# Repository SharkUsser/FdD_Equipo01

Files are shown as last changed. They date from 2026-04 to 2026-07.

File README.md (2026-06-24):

# Equipo 01 - Fundamentos de Diseño
### Carrera de Ingeniería Ambiental / Informática / Industrial  
**Universidad Peruana Cayetano Heredia**

---

## Sobre nosotros:  
Somos el **Equipo 01** del curso **Fundamentos de Diseño 2026-1**, conformado por estudiantes de las carreras de Ingeniería Ambiental, Informática e Industrial. 

Nuestro propósito es desarrollar soluciones tecnológicas aplicadas a problemáticas reales del sector agrícola en el Perú, específicamente relacionadas con el uso eficiente del agua y el manejo del suelo. A través de este proyecto, buscamos proponer alternativas innovadoras que permitan mejorar el monitoreo de las condiciones del suelo, optimizar el riego y contribuir a una agricultura más sostenible y productiva.

<p align="center">
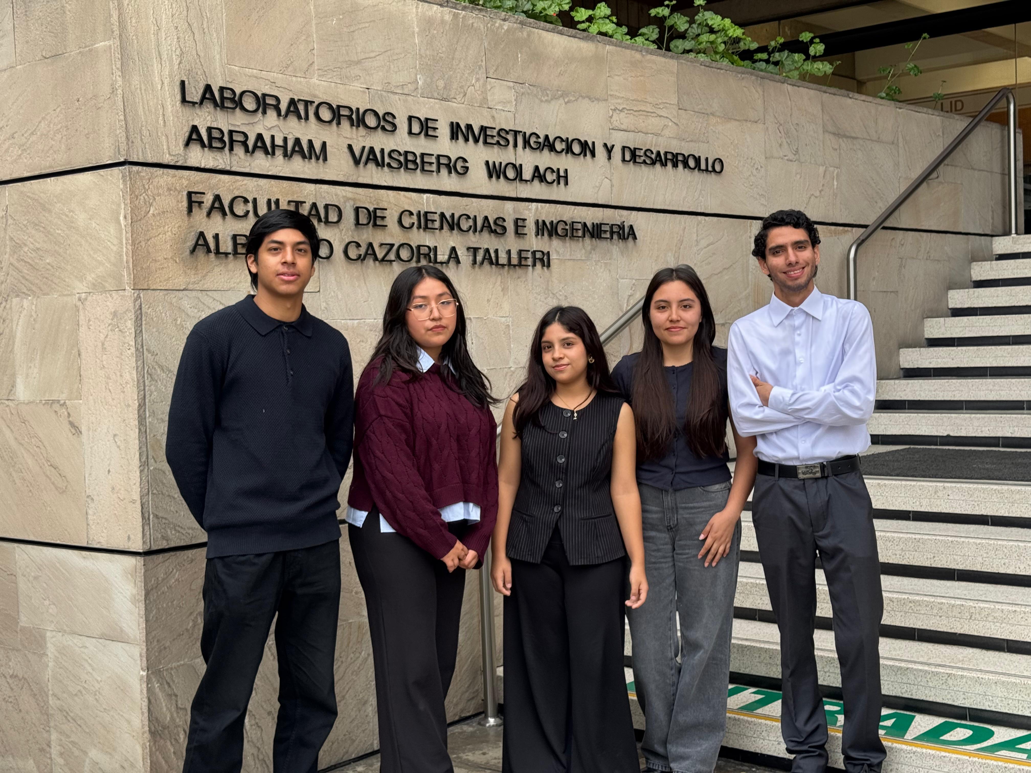
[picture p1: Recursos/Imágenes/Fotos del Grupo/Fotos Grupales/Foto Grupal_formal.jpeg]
imagen_alumnos

  <em>Figura 1. Fotografía del equipo 01</em>
</p>

---

## 👥 Integrantes del Equipo  

| Foto | Nombre | Rol | Intereses | Correo | 
|---|---|-----|---| --- |
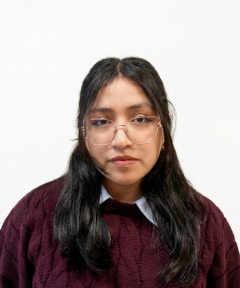
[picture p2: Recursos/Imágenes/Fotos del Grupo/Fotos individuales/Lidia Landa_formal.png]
|  | **Landa Torres, Lidia** | Líder del equipo - Gestión de proyecto tecnológico y ambiental | Innovación social, sostenibilidad, responsabilidad | lidia.landa@upch.pe | 
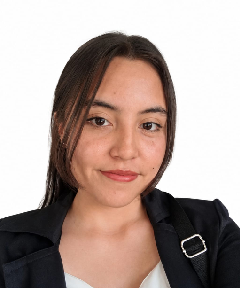
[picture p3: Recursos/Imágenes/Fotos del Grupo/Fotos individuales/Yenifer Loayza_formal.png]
|  | **Loayza Pineda, Yenifer** | Especialista en investigación ambiental y análisis de datos | Gestión ambiental, desarrollo comunitario y sostenible , Interpretación de datos ambientales | yenifer.loayza@upch.pe | 
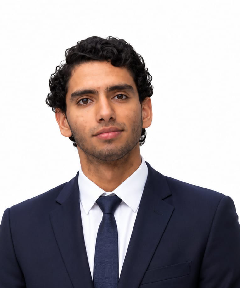
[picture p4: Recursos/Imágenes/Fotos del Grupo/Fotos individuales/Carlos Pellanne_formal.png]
|  | **Pellanne Aro, Carlos** | Diseñador de prototipo y desarrollador de sistemas | Diseño de prototipos, creatividad aplicada, investidación cientifica, análisis de datos | carlos.pellanne@upch.pe | 
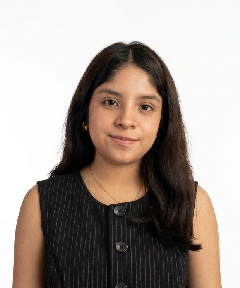
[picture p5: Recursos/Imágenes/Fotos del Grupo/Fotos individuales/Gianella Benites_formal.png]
|  | **Benites Tena, Gianella** | Especialista en documentación técnica y comunicación científica | Comunicación científica, redacción técnica | gianella.benites.t@upch.pe | 
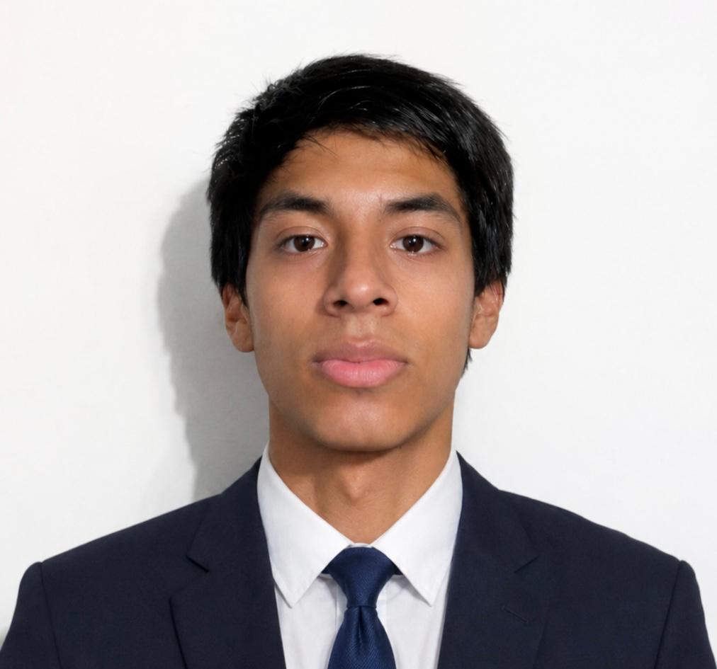
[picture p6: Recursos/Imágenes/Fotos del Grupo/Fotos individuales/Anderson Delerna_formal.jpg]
|  | **Delerna Infantes, Anderson** | Modelador de sistemas y analista de simulación | Programación, análisis de datos, simulación | anderson.delerna@upch.pe | 

---

## ¿Por qué este proyecto? 

En el Perú, la agricultura cumple un rol fundamental en el desarrollo del país y destaca por su gran diversidad de cultivos y condiciones climáticas. Sin embargo, pese a estas fortalezas, se enfrenta a un problema real: el uso ineficiente del agua en un contexto donde este recurso es escaso. En muchos casos, no se monitorea adecuadamente el estado del suelo, lo que genera desperdicio de agua, salinización y un menor rendimiento en los cultivos.

Como equipo, nos motivó abordar esta problemática desde una perspectiva práctica y preventiva, proponiendo el uso de sensores de humedad que permitan saber cuándo y cuánto regar. De esta manera, buscamos aportar a una mejor toma de decisiones, optimizar el uso del agua y contribuir a una agricultura más sostenible.

---

## Problemática

En el Perú, especialmente en la costa como Lima, la actividad agrícola se desarrolla en condiciones de limitada disponibilidad de agua, por lo que es fundamental usar este recurso de manera eficiente. Sin embargo, en la práctica, el riego no siempre se gestiona adecuadamente debido a la falta de monitoreo preciso del suelo, lo que dificulta tomar decisiones correctas en el manejo agrícola.

Esta problemática se hace evidente en zonas agrícolas donde los suelos presentan variabilidad en sus características, como baja materia orgánica, presencia de sales y limitada capacidad para retener agua. Estas condiciones influyen directamente en la disponibilidad de nutrientes y en la eficiencia del riego, por lo que requieren un manejo más específico que muchas veces no se aplica.

Actualmente, el riego suele basarse en métodos tradicionales que consideran valores promedio del suelo, sin tener en cuenta las diferencias dentro del terreno. Esto provoca que se aplique más o menos agua de la necesaria, generando un uso ineficiente del recurso hídrico. Cabe resaltar que, a nivel global, la agricultura consume cerca del 70% del agua dulce disponible, lo que evidencia la importancia de mejorar su gestión (EOS Data Analytics, “Uso del agua en agricultura”).

Diversos estudios señalan que un manejo inadecuado del riego puede provocar la acumulación de sales en el suelo, ya que el agua al evaporarse deja residuos salinos que afectan el crecimiento de los cultivos. De hecho, la FAO indica que la salinización es una de las principales causas de degradación del suelo a nivel mundial, reduciendo su productividad y sostenibilidad (FAO, 2021; Global Assessment of Salt-Affected Soils). Asimismo, el exceso de riego y un drenaje deficiente contribuyen al deterioro progresivo del suelo.

En consecuencia, la falta de herramientas que permitan monitorear de manera precisa las condiciones del suelo y optimizar el uso del agua de riego genera desperdicio de recursos, degradación del suelo y una menor productividad agrícola, poniendo en riesgo la sostenibilidad de esta actividad en el tiempo.

---

## Objetivo:
Como grupo, nuestro objetivo es optimizar el uso del agua de riego en sistemas agrícolas mediante el monitoreo de las condiciones del suelo y del estado de las plantas, con el fin de mantener su adecuado desarrollo y salud, mejorar la toma de decisiones en el manejo del riego, reducir el desperdicio hídrico y prevenir la degradación del suelo.

Objetivos específicos:

1. Medir y registrar la humedad del suelo en intervalos regulares mediante sensores, enviando los datos a una aplicación móvil que permita visualizar los niveles y establecer umbrales para activar o detener el riego.

2. Analizar el estado fisiológico de las plantas mediante imágenes captadas y procesadas en la aplicación con apoyo de inteligencia artificial, para detectar signos tempranos de estrés hídrico o crecimiento inadecuado.

3. Diseñar e implementar un sistema automatizado de riego controlado desde la aplicación, que integre los datos del suelo y de las plantas para ajustar la frecuencia y cantidad de agua aplicada, optimizando su uso.

---

## ODS en los que nos enfocamos:

Los Objetivos de Desarrollo Sostenible (ODS) son una iniciativa de la Organización de las Naciones Unidas orientada a abordar los principales desafíos globales como la pobreza, el cambio climático, la degradación ambiental y el acceso equitativo a recursos. Este proyecto se alinea de manera directa con varios de estos objetivos, al integrar tecnología avanzada en la gestión agrícola sostenible:

### ODS 6: Agua Limpia y Saneamiento
- **Definición:** Garantizar la disponibilidad y la gestión sostenible del agua y el saneamiento para todos.  
- **Relación:** El proyecto contribuye a una gestión más eficiente del agua en la agricultura, que es el sector con mayor consumo hídrico a nivel mundial. Mediante el uso de sensores de humedad y sistemas automatizados, se evita el riego innecesario, se reduce la sobreexplotación de fuentes hídricas y se promueve el uso racional del recurso. Además, ayuda a prevenir la contaminación del agua causada por el exceso de fertilizantes y lixiviación.

### ODS 9: Industria, Innovación e Infraestructura
- **Definición:** Construir infraestructuras resilientes, promover la industrialización sostenible y fomentar la innovación.  
- **Relación:** Este proyecto introduce tecnologías emergentes como el Internet de las Cosas (IoT) y el Deep Learning en el sector agrícola, especialmente en zonas rurales donde el acceso a estas herramientas es limitado. Esto no solo moderniza las prácticas agrícolas, sino que también impulsa la digitalización del campo, mejora la productividad y fortalece la competitividad del sector agroindustrial.

### ODS 12: Producción y Consumo Responsables
- **Definición:** Garantizar modalidades de consumo y producción sostenibles.  
- **Relación:** La implementación de sensores y análisis inteligente permite optimizar el uso de recursos como el agua, fertilizantes y pesticidas, reduciendo desperdicios y minimizando impactos negativos en el medio ambiente. Esto contribuye a una agricultura más eficiente, con menor huella hídrica y menor contaminación del suelo, promoviendo prácticas responsables a lo largo de toda la cadena productiva.

### ODS 15: Vida de Ecosistemas Terrestres
- **Definición:** Proteger, restaurar y promover el uso sostenible de los ecosistemas terrestres.  
- **Relación:** El proyecto combate procesos de degradación del suelo como la salinización y la desertificación mediante el monitoreo constante de la conductividad eléctrica (EC) y otras variables clave. Al prevenir daños estructurales en el suelo, se preserva su fertilidad a largo plazo, se mantiene la biodiversidad del ecosistema agrícola y se asegura la sostenibilidad de la producción en el tiempo.

---

##  Enfoque y sustento 

La agricultura es uno de los pilares del desarrollo económico del país, destacando por su gran diversidad de productos. Pese a esto, surge un problema en la inadecuada utilización de los recursos hídricos, especialmente en la costa peruana donde el agua es limitada. Actualmente, este es uno de los principales problemas, ya que no se monitorea adecuadamente el estado del suelo, lo que provoca que muchas veces se riegue de más o de menos. Esto no solo genera desperdicio de agua, sino que también va dañando el suelo con el tiempo.

A nivel mundial, la agricultura utiliza aproximadamente el 70% del agua dulce disponible, lo que evidencia la gran presión que ejerce este sector sobre los recursos hídricos y la necesidad de gestionarlos de manera eficiente, especialmente en zonas con escasez de agua (EOS Data Analytics, “Uso del agua en agricultura”). Asimismo, según la FAO, más del 20% de las tierras irrigadas en el mundo se encuentran afectadas por procesos de salinización, los cuales son provocados en gran medida por un riego inadecuado. Esta problemática constituye una de las principales formas de degradación del suelo, ya que disminuye su fertilidad, afecta el crecimiento de los cultivos y reduce significativamente su capacidad productiva (FAO, 2021; Global Assessment of Salt-Affected Soils).

Este problema genera diversos impactos que se encuentran estrechamente relacionados entre sí. El uso inadecuado del riego favorece la acumulación de sales en el suelo, lo que reduce progresivamente su fertilidad y afecta su capacidad para sostener cultivos de manera eficiente. Asimismo, cuando el suelo presenta un bajo contenido de materia orgánica, disminuye su capacidad de retener agua y nutrientes, lo que no solo incrementa el desperdicio hídrico, sino que también limita el desarrollo adecuado de las plantas (Labrador, 1993). Con el tiempo, estas condiciones pueden llevar a la degradación del suelo e incluso a la pérdida de áreas productivas.

Esta situación repercute directamente en la producción agrícola, generando inestabilidad en los cultivos y afectando la seguridad alimentaria, especialmente en zonas donde la agricultura es una actividad clave. A su vez, los agricultores se ven obligados a enfrentar mayores costos debido al uso excesivo de agua, la necesidad de aplicar más insumos para recuperar la calidad del suelo y la disminución en los rendimientos. En conjunto, estos efectos evidencian cómo una gestión ineficiente del riego no solo impacta el ambiente, sino también el ámbito social y económico.

Frente a esto, el proyecto propone analizar el suelo de manera más precisa y usar herramientas tecnológicas, como sensores de humedad, que permitan saber exactamente cuándo y cuánto regar. Así, se podrán tomar decisiones más informadas y adaptadas a cada zona del terreno.

Con este proyecto se logrará:
- Usar el agua de manera más eficiente, evitando desperdicios.
- Reducir problemas de salinización y degradación del suelo.
- Mejorar la productividad de los cultivos.
- Disminuir costos operativos para los agricultores.
- Tomar decisiones de riego basadas en datos reales del suelo.
- Promover una agricultura más sostenible y responsable con el medio ambiente.

En resumen, el proyecto combina tecnología y conocimiento del suelo para dar una solución práctica a un problema real, ayudando a mejorar tanto la producción agrícola como el cuidado de los recursos naturales.

---

## Nuestra propuesta

Se desarrolló un dispositivo inteligente de monitoreo y riego por goteo orientado al cultivo de arándanos en Huaral, Perú. El sistema es capaz de medir en tiempo real las condiciones del suelo, del agua de riego y del ambiente, procesar estos datos mediante un microcontrolador ESP32 y ejecutar acciones automáticas de riego, complementado con una pantalla LCD para visualización local de los datos.

El sistema se basa en tres componentes integrados:   
### 1. Monitoreo del suelo, agua y ambiente

El dispositivo incorpora sensores que miden:    
- Humedad del suelo (FC-28)
- Conductividad eléctrica del agua de riego, indicador de salinidad del agua antes de llegar al cultivo (TDS sensor)
- Temperatura y humedad ambiental (DHT11)

### 2. Control automatizado del riego

Los datos recolectados son procesados por el ESP32, que permite:   
- Comparar los valores medidos con umbrales definidos para el cultivo de arándanos
- Activar o detener la electrobomba de riego por goteo mediante un módulo relé de 2 canales
- Mostrar los datos en tiempo real en una pantalla LCD I2C

### 3. Sistema de energía autónomo

El prototipo opera de manera autónoma mediante:

- Batería Litio recargable con módulo cargador TP4056 (entrada USB Tipo-C)
- Elevador de tensión para garantizar el suministro estable de 5V al sistema
- Interruptor general para encendido y apagado del dispositivo

---

### ¿Qué haríamos con la información?

Al obtener los datos de humedad del suelo, conductividad eléctrica del agua de riego y temperatura/humedad ambiental, estos son procesados en tiempo real por el ESP32 y visualizados en la pantalla LCD integrada en el gabinete del prototipo. Esto permite al agricultor conocer de manera inmediata el estado del suelo y del agua de riego para tomar decisiones informadas.

A partir de esta información, el sistema permite:

- Activar o detener automáticamente el riego por goteo según los niveles de humedad del suelo medidos por el sensor FC-28.
- Monitorear la conductividad eléctrica del agua de riego mediante el sensor TDS, para detectar niveles elevados de salinidad en el agua antes de que llegue al cultivo, previniendo daños en los arándanos.
- Registrar las condiciones ambientales de temperatura y humedad como variables complementarias para una mejor interpretación del estado del cultivo.
- Optimizar el uso del agua aplicando únicamente la cantidad necesaria según las condiciones reales del suelo, evitando el sobre-riego y el desperdicio hídrico.

---

## Alcance

La optimización del uso del agua en el cultivo de arándanos en Huaral requiere sistemas que permitan monitorear con precisión las condiciones del suelo, del agua de riego y del ambiente en tiempo real. En este sentido, el proyecto desarrolló un prototipo físico funcional que integra un sensor de humedad del suelo (FC-28), un sensor de conductividad eléctrica del agua de riego (TDS) y un sensor de temperatura y humedad ambiental (DHT11), todos controlados por un microcontrolador ESP32, para facilitar una toma de decisiones más eficiente en el manejo del riego por goteo.

El sistema cuenta con un gabinete diseñado y fabricado mediante impresión 3D en material PETG, que aloja todos los componentes electrónicos y permite la instalación en campo mediante patas tipo estaca. Está dirigido a agricultores del sector que buscan reducir el desperdicio de agua y mejorar el manejo del riego de forma automatizada y accesible.

A corto plazo, el prototipo permite optimizar la aplicación del agua mediante datos precisos del suelo y del agua de riego en tiempo real. A largo plazo, el proyecto busca contribuir a reducir la salinización, prolongar la vida productiva del terreno y promover una gestión agrícola más sostenible en zonas de escasa disponibilidad hídrica como la costa peruana.

---

## Conclusión
El desarrollo del proyecto AgroSmart evidenció que el monitoreo preciso de las condiciones del suelo y del agua de riego es clave para mejorar la eficiencia del riego en el cultivo de arándanos en Huaral. La variabilidad de propiedades como la humedad del suelo y la salinidad del agua requiere estrategias más específicas que las empleadas en métodos tradicionales, los cuales no permiten responder a las necesidades reales de cada zona del terreno.

A través del diseño e implementación de un prototipo funcional, el equipo logró integrar sensores de humedad del suelo, conductividad eléctrica del agua de riego y temperatura/humedad ambiental en un sistema automatizado de riego por goteo, controlado por un ESP32 y alojado en un gabinete fabricado mediante impresión 3D. Este sistema permite tomar decisiones de riego basadas en datos reales, reducir el desperdicio hídrico y prevenir daños al cultivo por agua con niveles elevados de salinidad.

Esta experiencia nos permitió valorar la importancia de integrar sostenibilidad, ingeniería y tecnología para avanzar hacia una agricultura más eficiente, responsable y adaptada a las condiciones del contexto peruano.

---

## Reflexión
A lo largo de este proyecto, logramos comprender la importancia de usar el agua de manera eficiente en la agricultura, especialmente en contextos donde este recurso es limitado. También reconocimos que el uso de herramientas tecnológicas puede marcar una diferencia en la salud de las plantas y en la toma de decisiones relacionadas con el riego. 

Esta experiencia nos permitió valorar la necesidad de integrar sostenibilidad y tecnología para avanzar hacia una agricultura más eficiente y responsable.

---

## Referencias

## 📚 Referencias

- Instituto Nacional de Innovación Agraria (INIA). (2026). *Evaluación de la fertilidad de suelos en la Estación Experimental Agraria Donoso*.  
  http://hdl.handle.net/20.500.12955/3064  

- Isidoro, D. (2011). *Minimización de impactos en la agricultura de regadío. Riegos del Alto Aragón*.  
  http://hdl.handle.net/10532/1606  

- Labrador Moreno, J., y España Secretaría General de Estructuras Agrarias (Ed.). (1993). *La materia orgánica en los sistemas agrícolas: manejo y utilización*.  
  https://www.mapa.gob.es/ministerio/pags/biblioteca/hojas/hd_1993_03.pdf  

- FAO. (2024). *Global status of salt-affected soils* – Main report. Rome.  
  https://doi.org/10.4060/cd3044en

- FAO. (2024). *FAO launches first major global assessment of salt-affected soils in 50 years*  
  https://www.fao.org/newsroom/detail/fao-launches-first-major-global-assessment-of-salt-affected-soils-in-50-years/en

---

## 📌 Resumen Final
El presente README describe la conformación del equipo, la problemática abordada y la propuesta de solución desarrollada en el marco del curso Fundamentos de Diseño. El proyecto se enfoca en el uso ineficiente del agua en el riego agrícola debido a la falta de monitoreo preciso de las condiciones del suelo, especialmente en zonas como Huaral. 

En este contexto, se plantea el desarrollo de una solución tecnológica orientada al monitoreo de las propiedades del suelo, con el fin de optimizar el uso del agua de riego y mejorar la productividad agrícola. Esta propuesta busca integrar sostenibilidad, tecnología e innovación, contribuyendo a una gestión más eficiente de los recursos y a una agricultura más responsable.

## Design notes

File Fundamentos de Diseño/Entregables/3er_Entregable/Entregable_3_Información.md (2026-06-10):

# Entregable 03 – Diseño Final del Prototipo

<p align="center">
  <a href="https://github.com/SharkUsser/FdD_Equipo01/tree/main/FundDise%C3%B1o/Entregables/3er_Entregable%20Trabajado/M%C3%B3duloElectr%C3%B3nico">
    
  </a>
  <a href="https://github.com/SharkUsser/FdD_Equipo01/tree/main/FundDise%C3%B1o/Entregables/3er_Entregable%20Trabajado/M%C3%B3duloMec%C3%A1nico/Bocetos">
    
  </a>
  <a href="https://github.com/SharkUsser/FdD_Equipo01/tree/main/FundDise%C3%B1o/Entregables/3er_Entregable%20Trabajado/M%C3%B3duloMec%C3%A1nico/Onshape/Ensamble">
    
  </a>
  <a href="https://github.com/SharkUsser/FdD_Equipo01/tree/main/FundDise%C3%B1o/Entregables/3er_Entregable%20Trabajado/M%C3%B3duloMec%C3%A1nico/Onshape/Planos">
    
  </a>
  <a href="https://github.com/SharkUsser/FdD_Equipo01/tree/main/FundDise%C3%B1o/Entregables/3er_Entregable%20Trabajado/M%C3%B3duloMec%C3%A1nico/Onshape/Partes">
    
  </a>
</p>

---

## Descripción

El presente entregable reúne el desarrollo final del prototipo de riego inteligente. Se incluyen los esquemáticos electrónicos, los bocetos actualizados, el ensamblaje CAD del sistema, los planos técnicos y las partes destinadas a la fabricación mediante impresión 3D.

---

## Contenido del Entregable

### Esquemático Final

Diagrama electrónico completo del sistema incluyendo:

- Fuente de alimentación.
- Interruptor de encendido y apagado.
- ESP32.
- Sensores.
- Actuadores.
- Indicadores LED.
- Conectores y elementos auxiliares.

📄 **[Ver más detalles](https://github.com/SharkUsser/FdD_Equipo01/tree/main/FundDise%C3%B1o/Entregables/3er_Entregable%20Trabajado/M%C3%B3duloElectr%C3%B3nico)**

---

### Bocetos Actualizados

Bocetos finales desarrollados siguiendo el formato establecido en clase.

Incluye:

- Vista frontal.
- Vista lateral.
- Vista superior.
- Vista interior a color.

🎨 **[Ver más detalles](https://github.com/SharkUsser/FdD_Equipo01/tree/main/FundDise%C3%B1o/Entregables/3er_Entregable%20Trabajado/M%C3%B3duloMec%C3%A1nico/Bocetos)**  

---

### Ensamble 3D

Modelo CAD integrado del prototipo.

Incluye:

- Componentes electrónicos.
- Componentes mecánicos.
- Elementos de fijación.
- Caja contenedora.
- Distribución general del sistema.

🛠️ **[Ver más detalles](https://github.com/SharkUsser/FdD_Equipo01/tree/main/FundDise%C3%B1o/Entregables/3er_Entregable%20Trabajado/M%C3%B3duloMec%C3%A1nico/Onshape/Ensamble)**

---

### Planos Técnicos

Planos de fabricación de las piezas desarrolladas para el prototipo.

Incluye:

- Vistas técnicas.
- Dimensiones.
- Especificaciones de fabricación.

📐 **[Ver más detalles](https://github.com/SharkUsser/FdD_Equipo01/tree/main/FundDise%C3%B1o/Entregables/3er_Entregable%20Trabajado/M%C3%B3duloMec%C3%A1nico/Onshape/Planos)**

---

### Partes para Impresión 3D

Archivos STL de las piezas diseñadas para la fabricación del prototipo.

Incluye:

- Caja principal.
- Tapa.
- Soportes.

🧩 **[Ver más detalles](https://github.com/SharkUsser/FdD_Equipo01/tree/main/FundDise%C3%B1o/Entregables/3er_Entregable%20Trabajado/M%C3%B3duloMec%C3%A1nico/Onshape/Partes)**

---

## Objetivo

Documentar el diseño final del prototipo y proporcionar toda la información técnica necesaria para su fabricación, ensamblaje y validación.

---

## Estado del Proyecto

✅ Esquemático final completado.

✅ Bocetos finales completados.

✅ Ensamble CAD completado.

✅ Planos técnicos generados.

✅ Archivos STL preparados para impresión 3D.

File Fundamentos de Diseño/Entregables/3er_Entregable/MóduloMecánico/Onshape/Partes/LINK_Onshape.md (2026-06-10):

## 🔧 Modelo CAD

<p align="center">
  <a href="https://cad.onshape.com/documents/de819037ae2fdaa7c609af61/w/09385c61a574f4a0df1e0cfc/e/d54ca413b3f8b19aed0c8210" target="_blank">
    
  </a>
</p>

<p align="center">
  Accede al diseño CAD 3D desarrollado en Onshape.
</p>

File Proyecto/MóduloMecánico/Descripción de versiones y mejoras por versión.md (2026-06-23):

# Módulo Mecánico – Historial de Versiones

<p align="center">
  <a href="https://github.com/SharkUsser/FdD_Equipo01/tree/main/Proyecto/M%C3%B3duloMec%C3%A1nico/V_1.0">
    
  </a>
  <a href="https://github.com/SharkUsser/FdD_Equipo01/tree/main/Proyecto/M%C3%B3duloMec%C3%A1nico/V_2.0">
    
  </a>
  <a href="https://github.com/SharkUsser/FdD_Equipo01/tree/main/Proyecto/M%C3%B3duloMec%C3%A1nico/V_3.0">
    
  </a>
  <a href="https://github.com/SharkUsser/FdD_Equipo01/tree/main/Proyecto/M%C3%B3duloMec%C3%A1nico/V_4.0">
    
  </a>
  <a href="https://github.com/SharkUsser/FdD_Equipo01/tree/main/Proyecto/M%C3%B3duloMec%C3%A1nico/V_Final">
    
  </a>
</p>

## Descripción

El presente módulo reúne toda la documentación correspondiente al desarrollo mecánico del prototipo de riego inteligente. A lo largo de las distintas versiones se evidencia la evolución del diseño mediante la incorporación de mejoras estructurales, optimización de componentes y adecuaciones para su fabricación mediante impresión 3D.

Para cada versión se presentan los bocetos, ensamblajes CAD, partes modeladas y planos técnicos que sustentan el proceso de diseño. Adicionalmente, se incluye una carpeta con los certificados unificados de los integrantes del equipo como documentación complementaria del proyecto.

📄 **[Ver certificados de los integrantes](https://github.com/SharkUsser/FdD_Equipo01/tree/main/Proyecto/M%C3%B3duloMec%C3%A1nico/Certificados)**

## Navegación

- [Versión 1](#versión-1)
- [Versión 2](#versión-2)
- [Versión 3](#versión-3)
- [Versión 4](#versión-4)
- [Versión Final](#versión-final)

---
---

# **Versión 1**

## Descripción

Esta versión corresponde a la propuesta inicial del módulo mecánico del prototipo AgroSmart, desarrollada a partir de la semana 9 del curso. El equipo partió de un concepto de gabinete compartimentado, donde cada componente electrónico (batería, relé, pantalla LCD) tenía un espacio físico independiente dentro de la caja. Si bien el diseño estableció la forma general del gabinete y el sistema de patas tipo estaca para instalación en el suelo, aún no contemplaba una placa base común para el montaje de los componentes ni los requerimientos de acceso externo del sistema.

## Bocetos

Los bocetos presentan la propuesta de diseño correspondiente a esta versión del prototipo. Cada documento incluye vistas y anotaciones que permiten comprender la evolución del diseño mecánico.

🎨 **[Ver boceto](https://github.com/SharkUsser/FdD_Equipo01/tree/main/Proyecto/M%C3%B3duloMec%C3%A1nico/V_1.0/Bocetos)**  

## Onshape

### Planos

Los planos técnicos contienen la información dimensional necesaria para la fabricación de las piezas desarrolladas en esta versión.

📐 **[Ver planos](https://github.com/SharkUsser/FdD_Equipo01/tree/main/Proyecto/M%C3%B3duloMec%C3%A1nico/V_1.0/Onshape/Planos)**

---

### Ensamble

Primera propuesta de ensamble del módulo mecánico. El enfoque inicial consistió en organizar el gabinete por compartimentos independientes, dedicando un espacio físico separado a cada componente electrónico (batería LiPo, pantalla LCD, módulo relé y etapa de carga/elevador), sin contemplar aún el uso de una placa base donde montar todos los componentes en conjunto.

#### Cambios realizados en esta versión

- Definición de un gabinete dividido en compartimentos individuales por módulo (batería, LCD, relé, carga).
- Integración de la batería LiPo 503450 (1000 mAh) en un compartimento superior dedicado.
- Ubicación preliminar de la pantalla LCD y el módulo relé en compartimentos laterales independientes.
- Aún no se definía una placa de montaje común para los componentes; cada uno se alojaba de forma aislada dentro de su propio espacio.

🔗 **[Ver carpeta de ensamble](https://github.com/SharkUsser/FdD_Equipo01/tree/main/Proyecto/M%C3%B3duloMec%C3%A1nico/V_1.0/Onshape/Ensambles)**

🔗 **[Abrir modelo en Onshape](https://cad.onshape.com/documents/7030c5235228178de3d660d3/w/a4388209fd1fcbc84d7d1932/e/820ef67ac40d4f114fcb5abb)**

---

### Partes

Primera propuesta del gabinete mecánico. El diseño contemplaba un cuerpo prismático con tapa plana rectangular removible, interior dividido en compartimentos separados para cada componente electrónico (batería, relé, LCD), rejillas de ventilación en los laterales, y 4 patas tipo estaca compuestas por dos piezas separadas (palo + punta). La pantalla LCD se ubicó en la cara frontal en posición horizontal recta.

#### Cambios realizados en esta versión

- Diseño inicial del gabinete con tapa plana rectangular.
- Interior con compartimentos individuales separados para batería LiPo, módulo relé y pantalla LCD.
- Rejillas de ventilación modeladas en las caras laterales del gabinete.
- Patas tipo estaca de dos piezas independientes (palo y punta separados).
- Pantalla LCD integrada en la cara frontal en posición recta sin inclinación.

🔗 **[Ver carpeta de partes](https://github.com/SharkUsser/FdD_Equipo01/tree/main/Proyecto/M%C3%B3duloMec%C3%A1nico/V_1.0/Onshape/Partes)**

🔗 **[Abrir modelo en Onshape](https://cad.onshape.com/documents/7030c5235228178de3d660d3/w/a4388209fd1fcbc84d7d1932/e/5fcd48ab9844ea5e9363b70b)**

---

## Conclusión de la V_01

Esta primera versión permitió establecer la forma general del gabinete y la lógica de instalación en campo mediante patas tipo estaca. Sin embargo, el diseño por compartimentos separados resultó poco flexible para integrar los componentes sobre una base común, lo que motivó la reestructuración del interior en la siguiente versión.

---
---

# **Versión 2**

## Descripción

A partir de la retroalimentación recibida, el equipo replanteó la organización interna del gabinete, eliminando los compartimentos individuales y adoptando una placa base simuladora como superficie de montaje común para todos los componentes electrónicos. Este cambio representó un giro conceptual importante en el diseño: se pasó de un gabinete con espacios fijos por módulo a uno con un interior abierto y flexible. Adicionalmente se mejoraron detalles de la tapa (incorporación de reborde de encaje) y la pantalla LCD se inclinó para optimizar la visibilidad del usuario. El ensamble en esta etapa aún estaba incompleto, con varios componentes pendientes de integrar.

## Bocetos

Los bocetos presentan la propuesta de diseño correspondiente a esta versión del prototipo. Cada documento incluye vistas y anotaciones que permiten comprender la evolución del diseño mecánico.

🎨 **[Ver boceto](https://github.com/SharkUsser/FdD_Equipo01/tree/main/Proyecto/M%C3%B3duloMec%C3%A1nico/V_2.0/Bocetos)**  

## Onshape

### Planos

Los planos técnicos contienen la información dimensional necesaria para la fabricación de las piezas desarrolladas en esta versión.

📐 **[Ver planos](https://github.com/SharkUsser/FdD_Equipo01/tree/main/Proyecto/M%C3%B3duloMec%C3%A1nico/V_2.0/Onshape/Planos)**

---

### Ensamble

Se replanteó la lógica de montaje interno: en lugar de compartimentos separados por módulo, se incorporó una placa simuladora que serviría como base común para todos los componentes electrónicos, eliminando los módulos sueltos definidos en la V1. El ensamble en esta etapa aún no integraba todos los componentes del sistema.

#### Cambios realizados en esta versión

- Incorporación de una placa simuladora (representación genérica) como base de montaje para los componentes electrónicos.
- Eliminación de los compartimentos individuales por módulo definidos en la V1.
- Reubicación del módulo relé de 2 canales y la pantalla LCD sobre la nueva placa base.
- Ensamble aún incompleto: faltaban componentes del sistema por integrar sobre la placa.

🔗 **[Ver carpeta de ensamble](https://github.com/SharkUsser/FdD_Equipo01/tree/main/Proyecto/M%C3%B3duloMec%C3%A1nico/V_2.0/Onshape/Ensambles)**

🔗 **[Abrir modelo en Onshape](https://cad.onshape.com/documents/180f813292380060da21b0a8/w/799bce402b821ff8d6a71f8a/e/cbc91b82e484c4cc3304f300)**

---

### Partes

Se rediseñó el interior del gabinete eliminando los compartimentos separados para liberar el espacio interno y permitir el montaje sobre una placa base común. La tapa mantuvo su forma plana rectangular pero se le incorporó un reborde de encaje con la caja. La pantalla LCD se inclinó levemente hacia el usuario para mejorar su visibilidad. Se mantuvieron las patas tipo estaca de dos piezas y las rejillas laterales.

#### Cambios realizados en esta versión

- Eliminación de los compartimentos internos separados → interior abierto para montaje sobre placa base.
- Incorporación de reborde/relieve en la tapa para encaje con el cuerpo de la caja.
- Inclinación de la pantalla LCD para mejorar la visibilidad del usuario.
- Se mantiene la tapa plana rectangular y las patas de dos piezas de la V1.

🔗 **[Ver carpeta de partes](https://github.com/SharkUsser/FdD_Equipo01/tree/main/Proyecto/M%C3%B3duloMec%C3%A1nico/V_2.0/Onshape/Partes)**

🔗 **[Abrir modelo en Onshape](https://cad.onshape.com/documents/180f813292380060da21b0a8/w/799bce402b821ff8d6a71f8a/e/0b012dd8eeeb785c7095bbd8)**

---

## Conclusión de la V_02

La incorporación de la placa base simuladora como superficie de montaje común representó una mejora significativa en la organización interna del gabinete. No obstante, al tratarse de una representación genérica, el ensamble no reflejaba con fidelidad las dimensiones reales de los componentes, lo que se corrigió en la siguiente versión con la importación de una placa perforada real.

---
---

# **Versión 3**

## Descripción

Esta versión consolidó mejoras tanto en el ensamble como en el modelado de las partes. Se reemplazó la placa simuladora por una placa perforada (perfboard) real importada al modelo, logrando una representación más fiel del montaje físico. En cuanto a las partes, las patas pasaron de ser elementos de dos piezas a una pieza integrada, mejorando su resistencia estructural, y se incorporaron guías y separadores internos para el ordenamiento del cableado. El cambio más destacado fue el rediseño completo de la tapa: de forma plana a piramidal, con reborde de encaje y el nombre "AgroSmart" en relieve, decisión que se mantuvo hasta la versión final por su funcionalidad ante condiciones climáticas de lluvia.

## Bocetos

Los bocetos presentan la propuesta de diseño correspondiente a esta versión del prototipo. Cada documento incluye vistas y anotaciones que permiten comprender la evolución del diseño mecánico.

🎨 **[Ver boceto](https://github.com/SharkUsser/FdD_Equipo01/tree/main/Proyecto/M%C3%B3duloMec%C3%A1nico/V_3.0/Boceto)**  

## Onshape

### Planos

Los planos técnicos contienen la información dimensional necesaria para la fabricación de las piezas desarrolladas en esta versión.

📐 **[Ver planos](https://github.com/SharkUsser/FdD_Equipo01/tree/main/Proyecto/M%C3%B3duloMec%C3%A1nico/V_3.0/Onshape/Planos)**

---

### Ensamble

Se reemplazó la placa simuladora genérica por una placa perforada (perfboard) real importada al modelo, dando un paso hacia una representación más fiel del montaje físico. Se comenzaron a integrar componentes concretos sobre esta placa, aunque el ensamble todavía no incluía todos los elementos del sistema.

#### Cambios realizados en esta versión

- Importación de una placa perforada (perfboard) real en reemplazo de la placa simuladora de la V2.
- Montaje del módulo ESP32 sobre la placa perforada.
- Integración del módulo relé de 2 canales sobre la nueva placa.
- Componentes adicionales (sensor de humedad FC-28, soporte de batería, pantalla LCD) aún pendientes de ubicar dentro del ensamble.

🔗 **[Ver carpeta de ensamble](https://github.com/SharkUsser/FdD_Equipo01/tree/main/Proyecto/M%C3%B3duloMec%C3%A1nico/V_3.0/Onshape/Ensamble)**

🔗 **[Abrir modelo en Onshape](https://cad.onshape.com/documents/a687efca00635ecda8a33c39/w/773adb0243982b84ded61cc4/e/f08899861ca18ac6ea4649f5)**

---

### Partes

Se realizaron mejoras estructurales significativas en las patas y en la organización interna del cableado. Las patas pasaron de ser dos piezas separadas a una pieza integrada (palo y punta en una sola parte), mejorando la resistencia mecánica. Se agregaron separadores y guías para cables en el borde superior interior del gabinete. La tapa cambia de plana a piramidal, diseño que se mantiene hasta la versión final: la forma en punta favorece la escorrentía del agua de lluvia, evitando acumulación sobre el gabinete, e incorpora un reborde de encaje y el nombre "AgroSmart" en relieve.

#### Cambios realizados en esta versión

- Patas rediseñadas como pieza única integrada (palo y punta unidos), en reemplazo de las patas de dos piezas de V1 y V2.
- Incorporación de bases cuadradas planas en las patas para mayor estabilidad en el suelo.
- Adición de separadores y guías de cables en el borde superior interior del gabinete.
- Rediseño completo de la tapa: de plana rectangular a forma piramidal para escorrentía de lluvia.
- Incorporación de reborde de encaje en la tapa para ajuste con el cuerpo del gabinete.
- Texto "AgroSmart" en relieve sobre la tapa piramidal.

🔗 **[Ver carpeta de partes](https://github.com/SharkUsser/FdD_Equipo01/tree/main/Proyecto/M%C3%B3duloMec%C3%A1nico/V_3.0/Onshape/Partes)**

🔗 **[Abrir modelo en Onshape](https://cad.onshape.com/documents/a687efca00635ecda8a33c39/w/773adb0243982b84ded61cc4/e/e284b7302c0fb0b30b722042)**

---

## Conclusión de la V_03

La integración de la placa perforada real y el rediseño de las patas como pieza única elevaron la fidelidad del modelo respecto al prototipo físico esperado. El rediseño de la tapa a forma piramidal constituyó una decisión de diseño definitiva, orientada a la resistencia climática del gabinete en campo. Sin embargo, aún faltaba integrar todos los componentes electrónicos sobre la placa y definir los accesos externos del gabinete.

---
---

# **Versión 4**

## Descripción

Esta versión, presentada en la semana 13, fue la más completa hasta el momento y la que se llevó a fabricación física mediante impresión 3D. A partir de la retroalimentación del docente, se identificaron dos aspectos pendientes: la necesidad de incorporar un reservorio para el agua de riego y la integración de los componentes externos al gabinete (sensores que operan fuera de la caja). En cuanto al modelado de partes, se definieron todos los accesos y soportes del gabinete: compartimento para el sensor de temperatura, alojamiento interno para la batería, soportes para fijación de la placa perforada, apertura para el interruptor y orificio para el conector USB Tipo-C. El modelo de partes quedó definido en esta versión como definitivo.

## Bocetos

Los bocetos presentan la propuesta de diseño correspondiente a esta versión del prototipo. Cada documento incluye vistas y anotaciones que permiten comprender la evolución del diseño mecánico.

🎨 **[Ver boceto](https://github.com/SharkUsser/FdD_Equipo01/tree/main/Proyecto/M%C3%B3duloMec%C3%A1nico/V_4.0/Boceto)**  

## Onshape

### Planos

Los planos técnicos contienen la información dimensional necesaria para la fabricación de las piezas desarrolladas en esta versión.

📐 **[Ver planos](https://github.com/SharkUsser/FdD_Equipo01/tree/main/Proyecto/M%C3%B3duloMec%C3%A1nico/V_4.0/Onshape/Planos)**

---

### Ensamble

Se completó el conjunto de componentes internos sobre la placa perforada, alcanzando una distribución funcional consolidada dentro del gabinete. A partir de la retroalimentación del docente, se identificó la necesidad de incorporar elementos adicionales para el manejo del agua de riego, así como los componentes que operan fuera de la caja (sensores externos), los cuales no habían sido considerados hasta esta etapa.

#### Cambios realizados en esta versión

- Consolidación de todos los componentes internos sobre la placa perforada: módulo ESP32, módulo relé de 2 canales, pantalla LCD y conector de alimentación.
- Observación del docente: se requiere incorporar un reservorio/recipiente (retoplas) para el agua de riego.
- Identificación de la necesidad de modelar los componentes externos a la caja (sensores que sobresalen del gabinete), los cuales solo se habían considerado en su parte interna hasta esta versión.

🔗 **[Ver carpeta de ensamble](https://github.com/SharkUsser/FdD_Equipo01/tree/main/Proyecto/M%C3%B3duloMec%C3%A1nico/V_4.0/Onshape/Ensamble)**

🔗 **[Abrir modelo en Onshape](https://cad.onshape.com/documents/de819037ae2fdaa7c609af61/w/09385c61a574f4a0df1e0cfc/e/829537620e2ab074537002f9)**

---

### Partes

Versión donde se consolidaron todos los elementos de montaje y acceso externo del gabinete. Se incorporó un compartimento dedicado para el sensor de temperatura en la parte exterior, perforaciones y soportes internos para fijación de la placa perforada mediante tornillos, un compartimento interno para la batería, una apertura en la cara posterior para el interruptor de encendido/apagado, y un orificio pequeño en la parte lateral para el conector de carga USB Tipo-C. El modelado del gabinete quedó definido en esta versión y se mantuvo sin cambios en la Versión Final; las únicas modificaciones posteriores correspondieron al ensamble.

#### Cambios realizados en esta versión

- Incorporación de compartimento exterior dedicado para el sensor de temperatura (DHT22).
- Adición de compartimento interno para alojamiento fijo de la batería LiPo.
- Incorporación de soportes y orificios para tornillos de fijación de la placa perforada.
- Apertura en la cara posterior para el interruptor on/off accesible desde el exterior.
- Orificio pequeño en la cara lateral para el conector de carga USB Tipo-C.
- Orificios circulares en la cara posterior para paso de cables de sensores externos.
- Diseño del gabinete definido como definitivo; la Versión Final no presenta cambios en las partes, solo en el ensamble.

🔗 **[Ver carpeta de partes](https://github.com/SharkUsser/FdD_Equipo01/tree/main/Proyecto/M%C3%B3duloMec%C3%A1nico/V_4.0/Onshape/Partes)**

🔗 **[Abrir modelo en Onshape](https://cad.onshape.com/documents/de819037ae2fdaa7c609af61/w/09385c61a574f4a0df1e0cfc/e/d54ca413b3f8b19aed0c8210)**

---

## Conclusión de la V_04

La V4 representó la versión más madura del diseño mecánico y fue la única llevada a fabricación física mediante impresión 3D. La retroalimentación del docente permitió identificar dos elementos no contemplados hasta esta etapa: el reservorio de agua y los componentes externos del sistema, cuya integración al modelo se abordó en la Versión Final. El modelado del gabinete quedó consolidado y no requirió modificaciones posteriores.
---
---

# **Versión Final**

## Descripción

La Versión Final incorporó los comentarios recibidos tras la presentación de la V4. El modelado de las partes se mantuvo sin cambios respecto a la versión anterior, dado que el gabinete ya estaba correctamente definido. Los cambios se concentraron en el ensamble: se integraron los componentes externos del sistema (prensaestopas para paso de cables, sondas de sensores, sensor de conductividad TDS con carcasa protectora e interruptor on/off), completando así la representación del prototipo en su conjunto, tanto en su parte interna como en su interfaz con el entorno de cultivo.

## Bocetos

Los bocetos presentan la propuesta de diseño correspondiente a esta versión del prototipo. Cada documento incluye vistas y anotaciones que permiten comprender la evolución del diseño mecánico.

🎨 **[Ver boceto](https://github.com/SharkUsser/FdD_Equipo01/tree/main/Proyecto/M%C3%B3duloMec%C3%A1nico/V_Final/Boceto)**  

## Onshape

### Planos

Los planos técnicos contienen la información dimensional necesaria para la fabricación de las piezas desarrolladas en esta versión.

📐 **[Ver planos](https://github.com/SharkUsser/FdD_Equipo01/tree/main/Proyecto/M%C3%B3duloMec%C3%A1nico/V_Final/Onshape/Planos)**

---

### Ensamble

Versión consolidada del módulo mecánico, en la que se integraron los componentes externos identificados en la V4: prensaestopas (cable glands) para el paso de cables, sondas y sensores que sobresalen del gabinete hacia el sistema de riego, interruptor de encendido/apagado accesible desde el exterior, y el sensor de conductividad (TDS) con su carcasa protectora. Esta versión une el diseño interno (placa con componentes) con las interfaces externas necesarias para el funcionamiento real del sistema de riego.

#### Cambios realizados en esta versión

- Incorporación de prensaestopas (cable glands) para el paso sellado de cables y sondas hacia el exterior del gabinete.
- Acople de las sondas/sensores externos (temperatura, humedad de suelo) que sobresalen de la caja.
- Integración del sensor de conductividad (TDS) con su carcasa tipo malla en la parte externa.
- Incorporación del interruptor de encendido/apagado accesible desde el exterior del gabinete.
- Unificación completa de los componentes internos (placa, ESP32, relé, LCD) con los elementos externos del sistema de riego.

🔗 **[Ver carpeta de ensamble](https://github.com/SharkUsser/FdD_Equipo01/tree/main/Proyecto/M%C3%B3duloMec%C3%A1nico/V_Final/Onshape/Ensamble)**

🔗 **[Abrir modelo en Onshape](https://cad.onshape.com/documents/de819037ae2fdaa7c609af61/w/09385c61a574f4a0df1e0cfc/e/829537620e2ab074537002f9)**

---

### Partes

Las partes de la Versión Final son idénticas a las de la V4.0. No se realizaron modificaciones en el modelado del gabinete ni de sus componentes estructurales. Los cambios de esta versión corresponden exclusivamente al ensamble, donde se integraron los componentes externos (prensaestopas, sondas, sensor TDS e interruptor) al modelo completo del sistema.

#### Cambios realizados en esta versión

- Sin cambios en las partes respecto a la V4.0.
- El gabinete, la tapa piramidal, las patas y todos los elementos estructurales se mantienen idénticos.
- Las modificaciones de esta versión corresponden únicamente al ensamble (integración de componentes externos).

🔗 **[Ver carpeta de partes](https://github.com/SharkUsser/FdD_Equipo01/tree/main/Proyecto/M%C3%B3duloMec%C3%A1nico/V_Final/Onshape/Partes)**

🔗 **[Abrir modelo en Onshape](https://cad.onshape.com/documents/de819037ae2fdaa7c609af61/w/09385c61a574f4a0df1e0cfc/e/d54ca413b3f8b19aed0c8210)**

---

## Conclusión de la V_Final

La Versión Final consolidó el diseño mecánico completo de AgroSmart, integrando por primera vez los componentes externos al ensamble y unificando la representación interna y externa del sistema. Al mantener el modelado de partes de la V4 sin modificaciones, se evidencia que el diseño estructural del gabinete alcanzó su madurez en la versión anterior, siendo la Versión Final el resultado de la integración total del sistema en el entorno CAD.

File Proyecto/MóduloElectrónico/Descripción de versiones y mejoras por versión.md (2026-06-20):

# Módulo Electrónico – Historial de Versiones

## Descripción

Esta sección documenta la evolución del módulo electrónico del proyecto de riego inteligente. Se presentan las diferentes versiones desarrolladas durante el proceso de diseño, incluyendo las mejoras implementadas en cada etapa hasta llegar a la versión final.

---

## Versión 1

<p align="center">
  <a href="https://github.com/SharkUsser/FdD_Equipo01/tree/main/Proyecto/M%C3%B3duloElectr%C3%B3nico/V_1.0">
    
  </a>
</p>

### Descripción
Esta es la primera versión funcional completa del esquemático. Integra el ESP32 (U1) como unidad de control, conectado a los tres sensores (DHT11, TDS y FC-28) y a la pantalla LCD I2C mediante el bus SDA/SCL directamente desde los pines del microcontrolador, sin conversión de nivel lógico intermedia. El control del actuador se realiza mediante un módulo relé de un solo canal (RLY1, etiquetado U2) que acciona la electrobomba ("Bomba"). La etapa de energía está compuesta por el cargador TP4056 (módulo "CARGADOR1"), un elevador de tensión MT3608 ("ELEVADOR1") y una batería conectada mediante un conector de dos pines tipo AFC12-S02DCC-00. Se incluye además un divisor resistivo (R1 = 1.2k, R2 = 2k, R3 = 1k) asociado al control de un LED desde un GPIO del ESP32.

### Elementos característicos de esta versión:
- 	Relé de un solo canal (U2 / RLY1) en lugar de módulo de doble canal.
- 	Conexión directa de SDA/SCL del LCD a los pines del ESP32 (sin level shifter).
-	Conector de batería tipo barril AFC12-S02DCC-00.
-	Divisor de tensión con tres resistencias (R1, R2, R3) para gobierno del LED.
-	No existen borneras de alimentación independientes; las conexiones de potencia son directas.
-	No hay interruptor general ni LED indicador como bloque etiquetado aparte.

---

## Versión 2

<p align="center">
  <a href="https://github.com/SharkUsser/FdD_Equipo01/tree/main/Proyecto/M%C3%B3duloElectr%C3%B3nico/V_2.0">
    
  </a>
</p>

### Descripción
Se rediseña por completo la etapa de gestión de energía y la etapa de potencia del actuador. El módulo cargador pasa a ser un TP4056 con entrada USB Tipo-C (U8), reemplazando la versión anterior alimentada por conector de barril. Se incorporan dos borneras (J1) independientes: una para la batería y otra para la alimentación general de 5 V, lo que mejora la modularidad y facilidad de ensamblaje del circuito físico. El relé de canal único se reemplaza por un módulo relé de 2 canales (U9, "2 Channel Relay Module"), aunque en esta versión solo se utiliza un canal para accionar la bomba. Se elimina por completo el bloque del LED y su divisor resistivo (R1, R2, R3) presente en V1.0.

### Mejoras respecto a la Versión 1
- Cargador de batería: se sustituye el TP4056 genérico por un módulo TP4056 con entrada USB Tipo-C (U8).
- Conector de batería: cambia del conector de barril AFC12-S02DCC-00 a un conector JST de 2 pines simple, vía bornera.
- Se agregan dos borneras nuevas (J1): "Bornera" de alimentación de batería y "Bornera Alimentación 5V".
- Módulo relé: se reemplaza el relé de un canal (U2) por un módulo relé de 2 canales (U9).
- Se elimina el bloque LED y las resistencias R1/R2/R3 del divisor de tensión.
- Se elimina el elevador de tensión MT3608 como bloque independiente etiquetado ("ELEVADOR" se mantiene como nombre de referencia, integrado en la nueva configuración de carga).

---

## Versión 3

<p align="center">
  <a href="https://github.com/SharkUsser/FdD_Equipo01/tree/main/Proyecto/M%C3%B3duloElectr%C3%B3nico/V_3.0">
    
  </a>
</p>

### Descripción
Esta versión introduce los elementos de interacción manual del sistema. Se agrega un interruptor general (KEY1, tipo KEY_3x4X2_SMT) con su propia bornera (J1 "Interruptor"), que permite energizar o desenergizar el circuito de forma manual entre la batería y la línea +5V_P. Asimismo, se reincorpora un LED indicador (LED1) conectado directamente a un GPIO del ESP32, ahora documentado como bloque propio en la leyenda de componentes ("LED"). Se mantiene la arquitectura de energía de V2.0 (cargador TP4056 con USB Tipo-C, borneras de batería y alimentación) y el módulo relé de 2 canales (U9).

### Mejoras respecto a la Versión 2
-	Se añade un interruptor general (KEY1, KEY_3x4X2_SMT) con bornera "Interruptor" dedicada en la línea de alimentación de batería (+5V_P).
-	Se reincorpora el LED indicador (LED1), ahora etiquetado como bloque "LED" en la leyenda, conectado a un GPIO del ESP32.
-	Se actualiza la nomenclatura de la leyenda de bloques: se agregan las etiquetas "Módulo Relé" e "Interruptor" como bloques diferenciados.
-	Se mantiene sin cambios la etapa de carga (TP4056 + USB Tipo-C) y el relé de 2 canales introducidos en V2.0.

---

## Versión 4

<p align="center">
  <a href="https://github.com/SharkUsser/FdD_Equipo01/tree/main/Proyecto/M%C3%B3duloElectr%C3%B3nico/V_4.0">
    
  </a>
</p>

### Descripción
Se incorpora un cambio significativo a nivel de compatibilidad eléctrica: un Conversor de Nivel Lógico de 4 canales (LEVEL-SHIFTER-4CH), colocado entre el bus I2C del ESP32 (3.3 V) y la pantalla LCD (5 V), separando las señales en SDA/SCL (lado ESP32, 3.3 V) y SDA_LCD/SCL_LCD (lado LCD, 5 V). Esto corrige un riesgo de incompatibilidad de niveles lógicos que existía en las versiones anteriores, donde el LCD se alimentaba a 5 V pero recibía señales I2C de 3.3 V sin acondicionamiento. Adicionalmente, el LED indicador cambia de tecnología de montaje superficial a través-hueco (THT, D4) y se le agrega una resistencia pull-down R2 (10k) además de la resistencia limitadora R1 (330 Ω) ya existente, mejorando la estabilidad de la señal de control.

### Mejoras respecto a la Versión 3
-	Se agrega el Conversor de Nivel Lógico (LEVEL-SHIFTER-4CH) entre el ESP32 y el LCD I2C.
-	El bus I2C se divide en dos dominios de tensión: SDA/SCL (3.3 V, lado ESP32) y SDA_LCD/SCL_LCD (5 V, lado LCD), conectados a través del conversor de nivel.
-	El LED cambia de empaquetado SMD a tipo THT (referencia D4).
-	Se añade una resistencia pull-down R2 (10k) en la línea de control del LED, manteniendo la resistencia limitadora de corriente R1 (330 Ω).
-	Se actualiza la leyenda de bloques, incorporando "Conversor de Nivel Lógico" y "Resistencia pull-down" como elementos documentados.

---

## Versión Final

<p align="center">
  <a href="https://github.com/SharkUsser/FdD_Equipo01/tree/main/Proyecto/M%C3%B3duloElectr%C3%B3nico/V_Final">
    
  </a>
</p>

### Descripción
Esta es la versión consolidada y definitiva del esquemático para la entrega del proyecto. Mantiene íntegramente la arquitectura eléctrica de V4.0: conversor de nivel lógico para el bus I2C del LCD, LED indicador tipo THT con resistencias R1 (330 Ω) y R2 pull-down (10k), interruptor general, módulo relé de 2 canales y etapa de carga vía TP4056 con entrada USB Tipo-C. Los cambios respecto a V4.0 son de carácter organizativo y de presentación: se reordena la disposición textual de las etiquetas de bloques funcionales en la leyenda (intercambiando el orden visual de "Sensor de Humedad del Suelo" y "Conversor de Nivel Lógico"), sin que esto implique modificaciones en la conectividad eléctrica ni en los componentes del circuito.

### Mejoras respecto a la Versión 4
- •	Se reordena la posición de las etiquetas descriptivas de los bloques funcionales en la leyenda del esquemático, para mejorar la legibilidad y organización visual del documento.
- Se agrego etiqueta al interruptor.

---

## Cuadro Comparativo

| Elemento | Estado | Versión actual |
|---|---|---|
| Conector de batería | Conector tipo barril AFC12-S02DCC-00 (V1.0) | Bornera JST de 2 pines (desde V2.0) |
| Módulo cargador | TP4056 genérico (V1.0) | TP4056 con entrada USB Tipo-C — U8 (desde V2.0) |
| Elevador de tensión | MT3608 independiente ("ELEVADOR1", V1.0) | Integrado en la nueva etapa de carga (desde V2.0) |
| Borneras de alimentación | No existen (V1.0) | Bornera de batería + Bornera de 5V (desde V2.0) |
| Módulo relé | Relé de 1 canal (U2 / RLY1, V1.0) | Módulo relé de 2 canales (U9, desde V2.0) |
| LED indicador | Presente con divisor R1/R2/R3 (V1.0) → ausente (V2.0) | Reincorporado SMD (V3.0) → THT con pull-down (V4.0/FINAL) |
| Interruptor general | No existe (V1.0, V2.0) | KEY1 + bornera dedicada (desde V3.0) |
| Conversor de nivel lógico (I2C del LCD) | No existe — LCD conectado directo al ESP32 (V1.0–V3.0) | LEVEL-SHIFTER-4CH añadido (desde V4.0) |
| Organización de leyenda | Orden original de bloques | Reordenamiento visual sin cambio eléctrico (VFINAL) |

---

## Concluciones

- 	La evolución del esquemático de AgroSmart refleja un proceso de diseño iterativo orientado a mejorar la robustez eléctrica (incorporación del conversor de nivel lógico), la modularidad física (borneras independientes) y la usabilidad (interruptor general y LED indicador).
-	El cambio más relevante desde el punto de vista técnico es la introducción del conversor de nivel lógico en V4.0, que corrige una incompatibilidad de tensiones entre el bus I2C del ESP32 (3.3 V) y la pantalla LCD (5 V).
-	Las versiones V4.0 y VFINAL son eléctricamente equivalentes; la diferencia entre ambas es exclusivamente de organización y presentación de la leyenda de bloques funcionales.

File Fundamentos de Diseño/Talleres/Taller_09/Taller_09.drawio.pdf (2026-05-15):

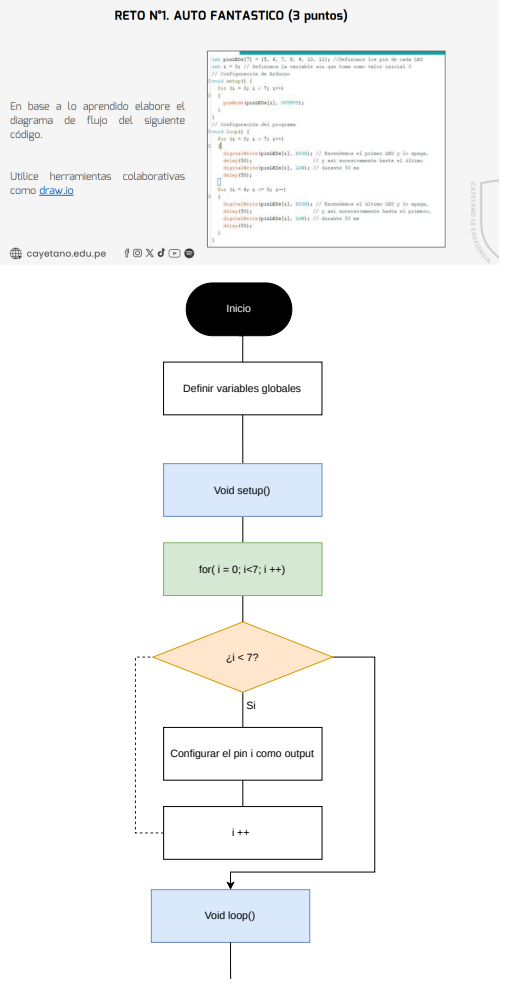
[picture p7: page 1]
Inicio; Void setup(); for( i = 0; i<7; i ++); Void loop()

Definir variables globales

Configurar el pin i como output

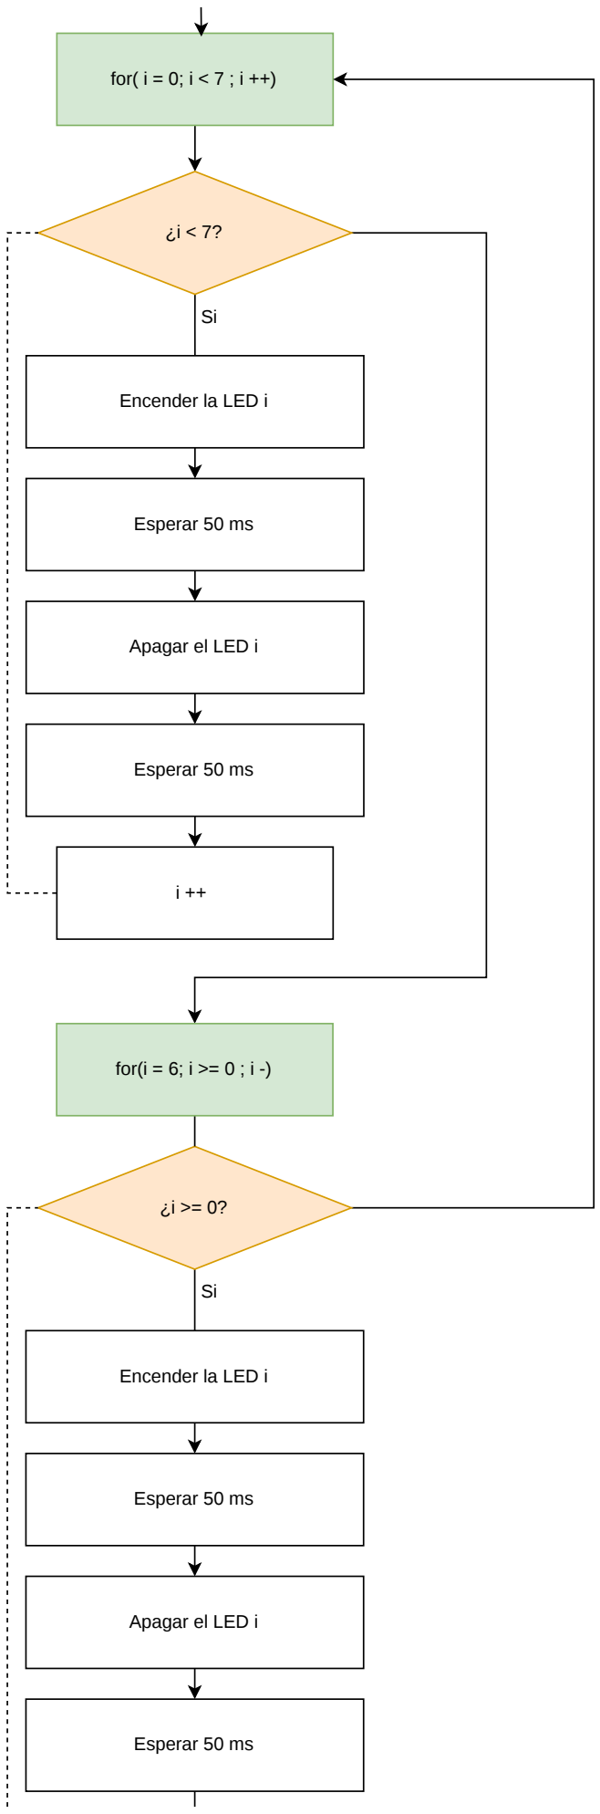
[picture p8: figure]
for( i = 0; i < 7 ; i ++); Encender la LED i; for(i = 6; i >= 0 ; i -); Esperar 50 ms; Apagar el LED i

i --

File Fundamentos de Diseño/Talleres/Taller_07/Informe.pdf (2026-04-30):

# UNIVERSIDAD PERUANA

# CAYETANO HEREDIA

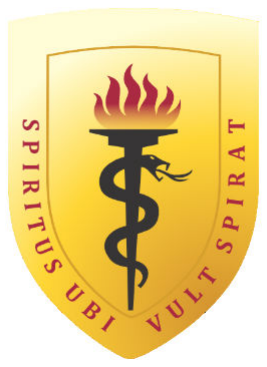
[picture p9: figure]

## FACULTAD DE CIENCIAS E INGENIERÍA “ALBERTO CAZORLA TALLERI”

### Departamento Académico de Ciencias Exactas - Sección Ingeniería

## INFORME TÉCNICO DEL PROYECTO

### Taller 07

## CURSO

Fundamentos de Diseño

## INTEGRANTES

Benites Tena, Gianella Yamile Landa Torres, Lidia Desairi Loayza Pineda, Yenifer

## PROFESORES

Marco Antonio Mugaburu Celi Jose Luiz Da Silva

## GRUPO

FDD - 1

Universidad Peruana Cayetano Heredia Facultad de Ciencias e Ingeniería Fundamentos de Diseño

## ÍNDICE

1. LISTA DE EXIGENCIAS | 2
2. ESTRUCTURAS DE FUNCIONES | 8
2.1. Caja Negra (Black Box) | 8
2.1.1. Entradas | 8
2.1.2. Salidas | 9
2.2. Secuencia de Operaciones | 9
2.2.1. Nivel usuario | 10
2.2.2. Nivel dispositivo | 11
2.3. Estructura de Funciones | 12
2.3.1. Dominio Electrónico | 12
2.3.2. Dominio Mecánico | 12
2.3.3. Dominio de Energía | 13
2.3.4. Dominio de Control | 13
2.3.5. Dominio de Actuación | 14
2.3.6. Dominio de Software | 14
2.4. Estructura de Funciones Integrada | 15
3. BOCETOS | 16
4. REFERENCIAS BIBLIOGRÁFICAS | 20

Página 1

Fundamentos de Diseño

### 1. LISTA DE EXIGENCIAS

Tabla 1. Lista de Exigencias

LISTA DE EXIGENCIAS

Pág 1 de 2

Edición: Rev. 3
PROYECTO: | AgroSmart: Sistema de Control y Optimización del Riego Agrícola

Fecha: 26/04/26
Revisado: 29/04/2026
CLIENTE: | Marco Antonio Mugaburu Celi Jose Luiz Da Silva. Domingo Vladimir Flores Robles Alberto Victor Alberto Huanambal Sovero Jhomer Rodrigo Contreras Paucca Harry Anderson Rivera Tito Renzo Jose Chan Rios Julissa Elvira Venancio Huerta Diana Sheyla Sandoval Eustaquio Cristhian Gustavo Jacinto Calderon | Elaborado: Benites Tena, Gianella Landa Torres, Lidia Loayza Pineda, Yenifer
Fecha | Deseo o Exigencia | DESCRIPCIÓN | Responsable
26/04/202 6 | E | FUNCIÓN PRINCIPAL: | Todos
Monitorear en tiempo real la humedad, temperatura e impedancia eléctrica del suelo en el cultivo de arándanos y controlar automáticamente el riego por goteo cuando los valores estén fuera de los niveles establecidos, optimizando el uso del recurso hídrico según criterios de eficiencia en sistemas de riego (ISO 46001:2019) (1) (https://www.zotero.org/google-docs/?FNWrv3) y prácticas agrícolas recomendadas por la FAO (2,3), (https://www.zotero.org/google-docs/?obCidZ) así como lineamientos de eficiencia en riego por goteo (4). (https://www.zotero.org/google-docs/?h8MJcO) Además, permitir la visualización y análisis de los datos mediante una plataforma digital.

Página 2

Fundamentos de Diseño

26/04/2026 E

GEOMETRÍA:

LL

El sistema debe contar con un módulo compacto que permita su instalación en campo agrícola, con dimensiones aproximadas no mayores a 20 × 15 × 10 cm, facilitando la integración de los componentes electrónicos y sensores. Además, debe permitir la correcta ubicación de los sensores en el suelo para obtener mediciones representativas.(5) (https://www.zotero.org/google-docs/?VsrHfQ)

26/04/202
6

E

FUERZAS:

GB

El sistema debe resistir condiciones ambientales propias del entorno agrícola, incluyendo exposición al viento, humedad y manipulación durante su instalación. Asimismo, debe contar con protección mínima IP65 contra polvo y agua, garantizando su durabilidad y funcionamiento continuo en campo.(4,5) (https://www.zotero.org/google-docs/?bgEHHi)

26/04/202
6

E

ENERGÍA:

GB

Alimentación eléctrica: El sistema deberá operar con una tensión de entrada de 5 V DC (mediante conexión USB) o a través de una batería recargable en el rango de 3.7 V a 5 V. Asimismo, el consumo energético en condiciones normales de operación no deberá superar los 2 W, con el fin de garantizar su compatibilidad con fuentes de energía autónomas, como paneles solares de baja potencia. (6,7) (https://www.zotero.org/google-docs/?q4S2qS)

26/04/202
6

D

Fuente solar: Se desea incorporar un panel solar pequeño (~5W) para garantizar autonomía energética en campo abierto sin necesidad de red eléctrica.

GB

Página 3

Fundamentos de Diseño

26/04/202
6

E

SEÑALES:

TODOS

Entradas:
Energía eléctrica
Energía del dispositivo móvil Señal/datos de humedad del suelo Señal/datos de temperatura Señal/datos de conductividad eléctrica Datos de conectividad
Configuración del usuario
Comandos desde la app
Señal de encendido/apagado

26/04/202
6

E

Salidas:
Alertas al agricultor
Recomendaciones de riego
Visualización de datos
Confirmación del estado (activo/inactivo) Señal de activación de bomba
Señal de encendido/apagado ejecutada Datos procesados enviados a la app
Agua distribuida al cultivo (riego activado) Energía calórica (efecto secundario del sistema)

26/04/202
6

E

ELECTRONICA (Hardware)

YL

El sistema debe contar con un módulo Arduino UNO encargado de recibir y procesar los datos de los sensores de humedad del suelo, temperatura e impedancia eléctrica. Además, debe incluir un relé para activar o desactivar la bomba de agua según los valores establecidos para el riego automático.(7,8) (https://www.zotero.org/google-docs/?xEdQwr)

26/04/202
6

E

El sistema debe incorporar sensores instalados en el cultivo de arándanos para medir las condiciones del suelo en tiempo real y enviar la información a una plataforma digital para su monitoreo.

LL

Página 4

Fundamentos de Diseño

| | SOFTWARE:
26/04/202 6 26/04/202 6 26/04/202 6 | E E E | El programa debe leer los datos de los sensores, controlar el riego automático y gestionar el envío de información. (8,9) (https://www.zotero.org/google-docs/?oCFUUL) El sistema debe mostrar en tiempo real los valores de humedad, temperatura e impedancia eléctrica tanto en una pantalla LCD como en una aplicación web o móvil. La aplicación debe guardar el historial de riegos y permitir visualizar los datos para mejorar el uso del agua. El sistema debe enviar notificaciones cuando los valores estén fuera de los rangos establecidos. | YL GB LL
26/04/202 6 | E | COMUNICACIONES: | GB
El sistema debe permitir la transmisión de datos de los sensores hacia una plataforma digital cuando exista conexión a internet. En ausencia de conectividad, el sistema debe operar de manera autónoma, almacenando la información localmente y mostrando los datos en tiempo real mediante una interfaz, garantizando el monitoreo continuo en zonas agrícolas.

14/05/202
6

E

SEGURIDAD:

YL

El sistema debe proteger los datos almacenados mediante mecanismos de seguridad para evitar accesos no autorizados.(10) (https://www.zotero.org/google-docs/?6jwC9r)

14/05/202
6

E

ERGONOMÍA:

YL

El sistema debe contar con un diseño compacto y seguro, evitando bordes filosos y facilitando su manipulación e instalación en campo agrícola.

Página 5

Fundamentos de Diseño

26/04/202
6

E

FABRICACIÓN:

GB

El sistema debe integrar un nodo de monitoreo basado en un microcontrolador (Arduino) y sensores de humedad, temperatura e impedancia eléctrica, ensamblados en una unidad compacta. El módulo debe contar con un encapsulado con grado de protección mínimo IP65, que garantice resistencia al polvo y a la humedad en condiciones de campo agrícola. Asimismo, debe permitir la disipación térmica, contar con sellado adecuado de conexiones eléctricas y facilitar labores de mantenimiento.

26/04/202
6

E

CONTROL DE CALIDAD:

LL

El sistema debe garantizar una precisión adecuada en la medición de humedad, temperatura e impedancia eléctrica del suelo, con tolerancias acordes a sensores utilizados en aplicaciones agrícolas.
26/04/202 6 | E | Pruebas de campo: El prototipo deberá ser validado en condiciones reales de suelo en Huaral, verificando la exactitud de lecturas, autonomía energética y estabilidad de la comunicación durante al menos 72 horas continuas. | LL
26/04/202 6 | E | MONTAJE:
El módulo debe permitir su instalación en campo agrícola, asegurando una correcta fijación de los sensores en el suelo y una ubicación adecuada del nodo de control.

26/04/202
6

D

TRANSPORTE:

LL

El sistema debe ser ligero y compacto, permitiendo su fácil traslado e instalación por una sola persona en el entorno agrícola, con un peso aproximado no mayor a 3 kg.

Página 6

Fundamentos de Diseño

26/04/202
6

E

USO:

GB

Condiciones de operación: El sistema deberá funcionar correctamente en condiciones climáticas de la costa peruana: temperatura ambiente de 15°C a 35°C, humedad relativa de hasta 90% y exposición a polvo y salpicaduras de agua de riego.
26/04/202 6 | E | Autonomía continua: El sistema deberá operar de forma ininterrumpida las 24 horas del día, los 7 días de la semana, sin intervención manual. | GB
28/05/202 6 | E | MANTENIMIENTO: | YL
Limpieza periódica del módulo y sensores para evitar acumulación de polvo, tierra y humedad propios del entorno agrícola. Se debe verificar periódicamente el estado de las conexiones, sensores y sistema de alimentación. Los sensores deben limpiarse y calibrarse para evitar lecturas erróneas por suciedad o deterioro.

26/05/202
6

E

COSTOS:

GB

Costo del prototipo: El costo total del prototipo, incluyendo hardware y componentes, no deberá exceder los S/ 500.00, con el objetivo de garantizar su viabilidad económica como una solución accesible para pequeños y medianos agricultores de la zona de Huaral.
26/04/202 6 | D | Costo de escala: Se desea que en producción en serie el costo por unidad no supere los S/. 250.00, permitiendo su adopción masiva en el sector agrícola. | GB
26/04/202 6 | E | PLAZOS: | Todos
La entrega del dispositivo funcional está programada para el 2 de julio de 2026, correspondiente a la semana 16 del calendario académico UPCH.

Página 7

Fundamentos de Diseño

### 2. ESTRUCTURAS DE FUNCIONES

2.1. Caja Negra (Black Box)

La caja negra del sistema AgroSmart representa una abstracción funcional en la que se identifican las magnitudes de entrada y salida sin detallar el funcionamiento interno. Estas magnitudes se clasifican en energía, materia y señales, de acuerdo con la metodología VDI 2221.
Dado que el sistema está compuesto por un dispositivo físico y una aplicación móvil, se realiza la separación en dos subsistemas para un mejor análisis.

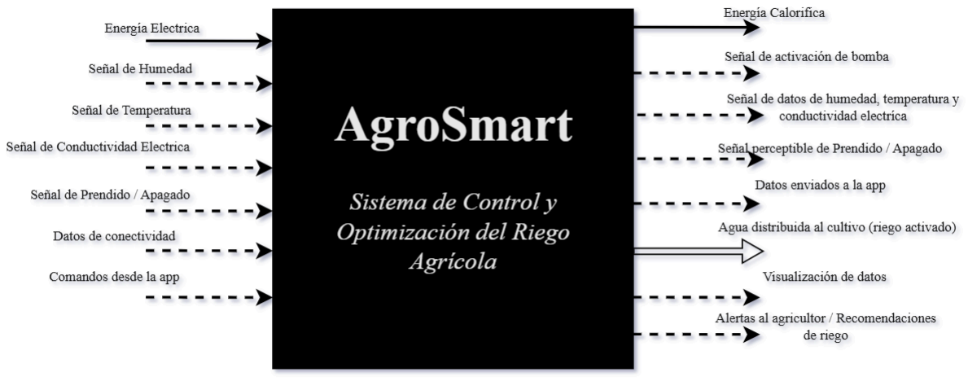
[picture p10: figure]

Imagen 1. Caja negra
Fuente: Creación propia
2.1.1. Entradas
- Energía eléctrica
- Señal de humedad del suelo (0–100% VWC)
- Señal de temperatura (0°C – 60°C)
- Señal de conductividad eléctrica aparente (CEa)
- Comandos del usuario desde la aplicación (configuración, umbrales)
- Datos de conectividad (Wi-Fi / red móvil)
- Señal de encendido/apagado

Página 8

Fundamentos de Diseño

2.1.2. Salidas
- Recomendaciones de riego / Alertas al usuario (condiciones críticas de humedad, temperatura o salinidad)
- Visualización de datos (gráficos e interfaz)
- Señal de encendido/apagado enviada al dispositivo
- Energía calorífica
- Agua distribuida al cultivo (riego activado)
- Activación de bomba de riego
- Datos enviados a la aplicación (humedad, temperatura, CEa, timestamp)
- Estado del sistema (encendido/apagado)
2.2. Secuencia de Operaciones

La secuencia de operaciones describe el proceso de funcionamiento del sistema AgroSmart de manera ordenada, diferenciando dos niveles: el nivel usuario y el nivel dispositivo. Esta distinción permite identificar claramente las interacciones externas y las funciones internas del sistema.

Página 9

Fundamentos de Diseño

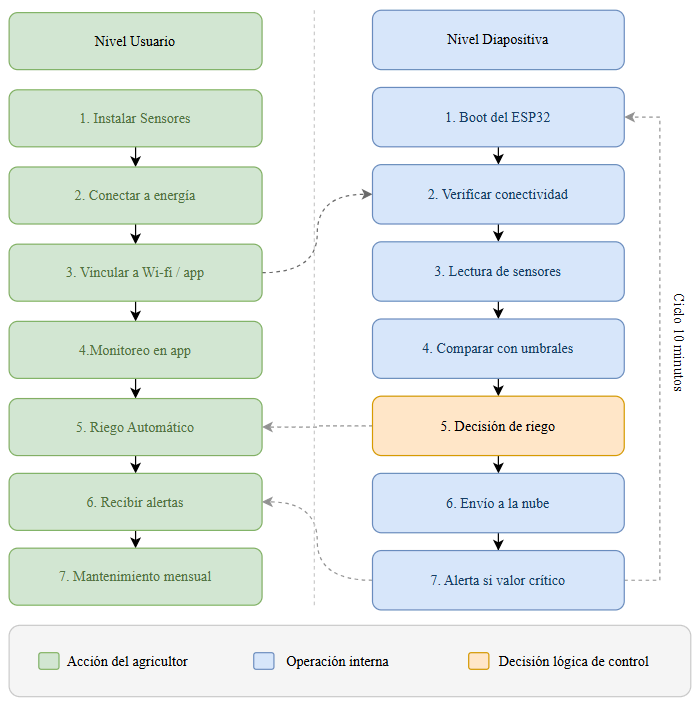
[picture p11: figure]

Diagrama 1. Secuencia de operaciones del sistema AgroSmart Fuente: Creación propia

2.2.1. Nivel usuario

El nivel usuario describe la interacción del agricultor con el sistema desde la instalación hasta la operación y mantenimiento.
a. El agricultor instala el módulo de sensores en la zona radicular del cultivo de arándano (hasta 30 cm de profundidad, sin herramientas especiales).
b. Conecta la estación central (ESP32) a la fuente de energía.
c. Descarga e instala la aplicación móvil o accede a la plataforma web AgroSmart.
d. Vincula el dispositivo a la red Wi-Fi del entorno mediante la aplicación.
e. Configura los parámetros de operación, incluyendo umbrales de humedad, temperatura y conductividad eléctrica según el cultivo.
f. Activa el sistema desde la aplicación, iniciando el monitoreo automático.
g. Visualiza en tiempo real los datos del suelo (humedad, temperatura y CEa) a través de la interfaz.

Página 10

Fundamentos de Diseño

h. Recibe recomendaciones de riego generadas por el sistema en función de los datos analizados.
i. Recibe notificaciones ante condiciones críticas y, si lo desea, interviene manualmente activando o desactivando el riego desde la aplicación.
j. Realiza mantenimiento periódico, retirando, limpiando y reinstalando los sensores.
2.2.2. Nivel dispositivo

El nivel dispositivo describe el funcionamiento interno del sistema desde el encendido hasta la ejecución automática del riego.
a. El sistema se energiza y el microcontrolador ejecuta el firmware de inicio (boot).
b. Se verifica la conectividad a la red (Wi-Fi o SIM); en caso de fallo, se realizan intentos de reconexión automática.
c. Se activan los sensores y se realiza la adquisición de datos: humedad del suelo (VWC), temperatura (°C) y conductividad eléctrica aparente (CEa).
d. Las señales analógicas son acondicionadas y convertidas a formato digital.
e. El sistema procesa los datos obtenidos de los sensores.
f. Se comparan los valores medidos con los umbrales configurados.
g. Se toma una decisión de control:
i. Si la humedad es menor al umbral mínimo → se activa la electroválvula o bomba de riego.
ii. En caso contrario → el sistema mantiene el riego desactivado.
h. Se genera la trama de datos con los valores medidos y se transmite al servidor mediante protocolos de comunicación.
i. Se monitorean condiciones críticas y se generan alertas en caso de valores fuera de rango.
j. El sistema entra en espera hasta el siguiente ciclo de medición, repitiendo el proceso de forma continua.

Página 11

Fundamentos de Diseño

2.3. Estructura de Funciones

La estructura de funciones descompone la función global del sistema AgroSmart en un conjunto de subfunciones organizadas por dominios, permitiendo identificar el flujo de energía (E), materia (M) y señales (S) entre ellas.
Esta representación facilita la comprensión del funcionamiento interno del sistema y sirve como base para el desarrollo de soluciones técnicas.
2.3.1. Dominio Electrónico
Subfunción | Descripción

Medir humedad del
suelo
| Captura la señal de contenido volumétrico de agua
| (0–100% VWC) en la zona radicular

Medir temperatura del
suelo
| Registra la temperatura del suelo en un rango de
| 0–60°C con resolución aproximada de ±0.5°C
Medir impedancia eléctrica (CEa) | Estima la conductividad eléctrica aparente del
| suelo (0–5 dS/m) como indicador de salinidad
Acondicionar señal de sensores | Amplifica, filtra y digitaliza las señales analógicas
| provenientes de los sensores
Activar electroválvula / bomba | Emite una señal digital de control (HIGH/LOW)
| para la apertura o cierre del sistema de riego
2.3.2. Dominio Mecánico
Subfunción | Descripción
Sostener módulo sensor en suelo | Mantiene la posición del sensor en la zona
| radicular (hasta 30 cm de profundidad, diámetro
máximo 5 cm)

Página 12

Fundamentos de Diseño

Proteger electrónica del
entorno

Encapsula los circuitos con sellado mínimo IP54, resistente a polvo y salpicaduras

Soportar cargas de
compactación

La carcasa resiste fuerzas del suelo, tránsito peatonal y herramientas agrícolas

Permitir extracción y
reinserción

Diseño modular que permite retirar, limpiar y reinstalar los sensores sin herramientas

2.3.3. Dominio de Energía
Subfunción | Descripción
Recibir energía eléctrica | Acepta entrada de 5V DC (USB) o batería de 3.7–5V
Convertir y regular tensión | Convierte y estabiliza el voltaje para alimentar el sistema (DC/DC)
Almacenar energía | Utiliza batería recargable como fuente principal o de respaldo
Captar energía solar | Panel solar (~5W) para recarga autónoma en campo
Proteger ante sobretensión / cortocircuito | Incluye circuitos de protección ante fallas eléctricas
2.3.4. Dominio de Control
Subfunción | Descripción

Página 13

Fundamentos de Diseño

Procesar datos de sensores | El sistema recibe y procesa las lecturas de los sensores
Comparar valores con umbrales | Evalúa si los parámetros están dentro de los rangos configurados
Decidir activación de riego | Determina la apertura o cierre del sistema de riego
Transmitir datos a la nube | Envía datos mediante Wi-Fi usando protocolos de comunicación
Gestionar fallos de conexión | Realiza reconexión automática o cambio de red
Generar alertas | Detecta condiciones críticas y activa notificaciones
2.3.5. Dominio de Actuación
Subfunción | Descripción
Recibir señal de control | Recibe la orden digital desde el dominio de control (activar/desactivar riego).
Activar sistema de riego | Acciona la electroválvula o bomba según la señal recibida.
Controlar flujo de agua | Regula el paso de agua hacia el cultivo.
Aplicar riego | Entrega agua al suelo en la zona radicular.
2.3.6. Dominio de Software
Subfunción | Descripción

Página 14

Fundamentos de Diseño

Ejecutar firmware del
sistema

Gestiona la lógica de operación y ciclos de monitoreo

Visualizar datos en la app | Muestra información en tiempo real y datos históricos
Interpretar estado del suelo | Presenta indicadores visuales para facilitar la comprensión
Enviar alertas automáticas | Notificaciones ante condiciones fuera de rango
Autodiagnóstico del sistema | Supervisa batería, conectividad y estado general
Proteger comunicación | Implementa protocolos de seguridad
| (TLS/HTTPS)
2.4. Estructura de Funciones Integrada

La estructura de funciones integrada de AgroSmart articula los cinco dominios en un flujo continuo de energía, materia y señales que parte desde la captación de energía y medición del suelo, hasta la activación del riego y la visualización de datos en la aplicación del agricultor.

Página 15

Fundamentos de Diseño

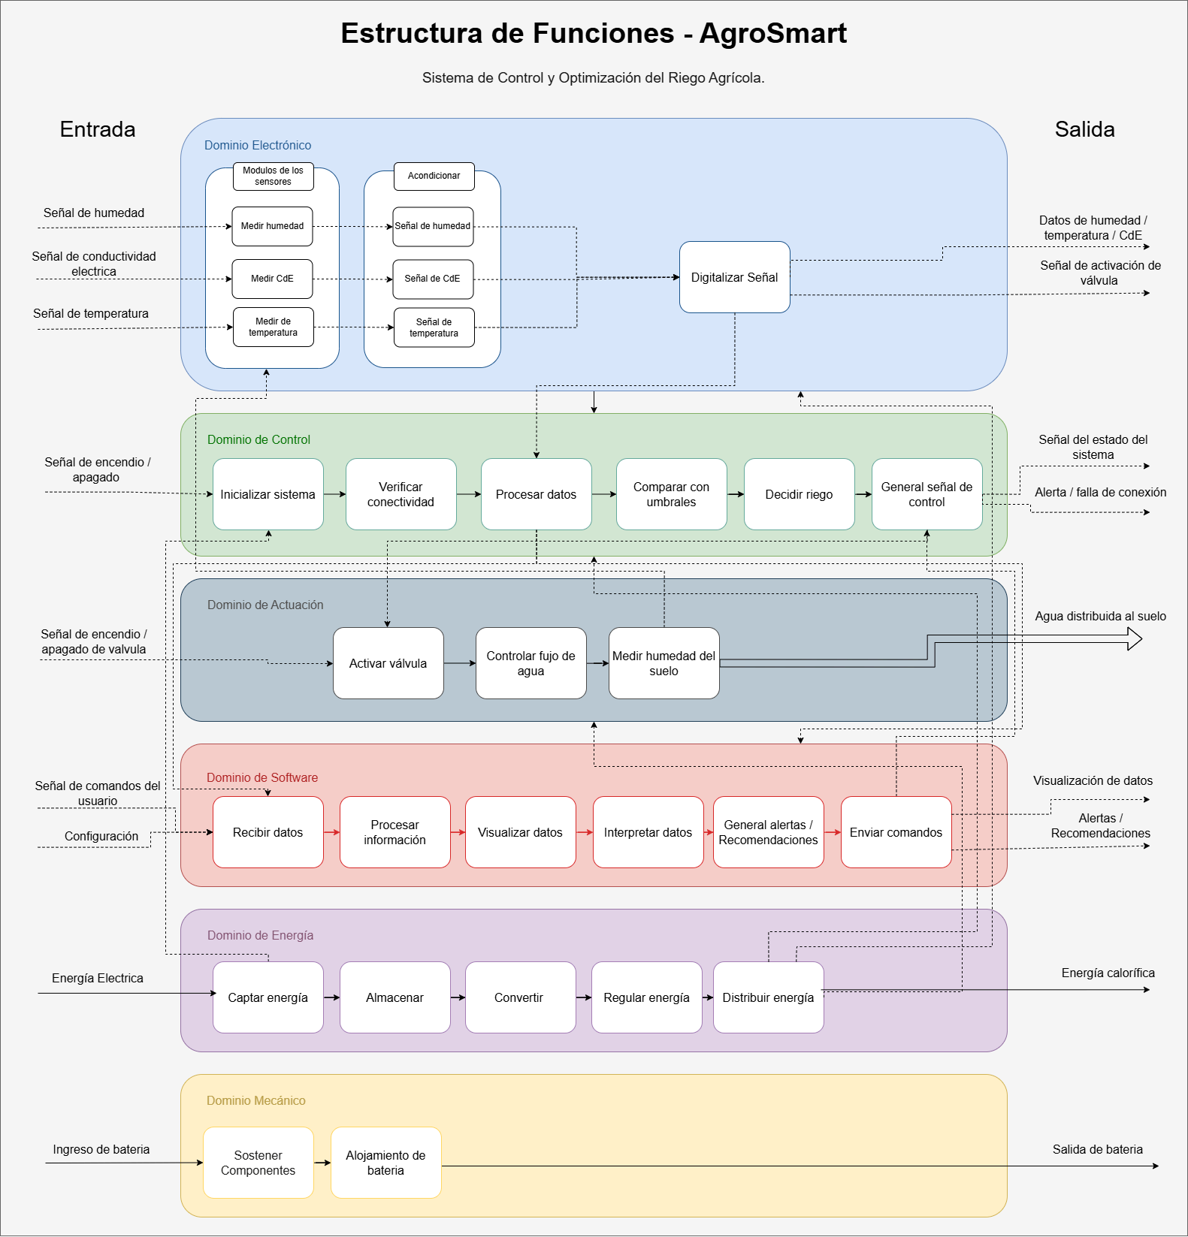
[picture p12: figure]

Diagrama 2. Estructura de funciones Fuente: Creación propia

### 3. BOCETOS

3.1. Boceto 1

Página 16

Fundamentos de Diseño

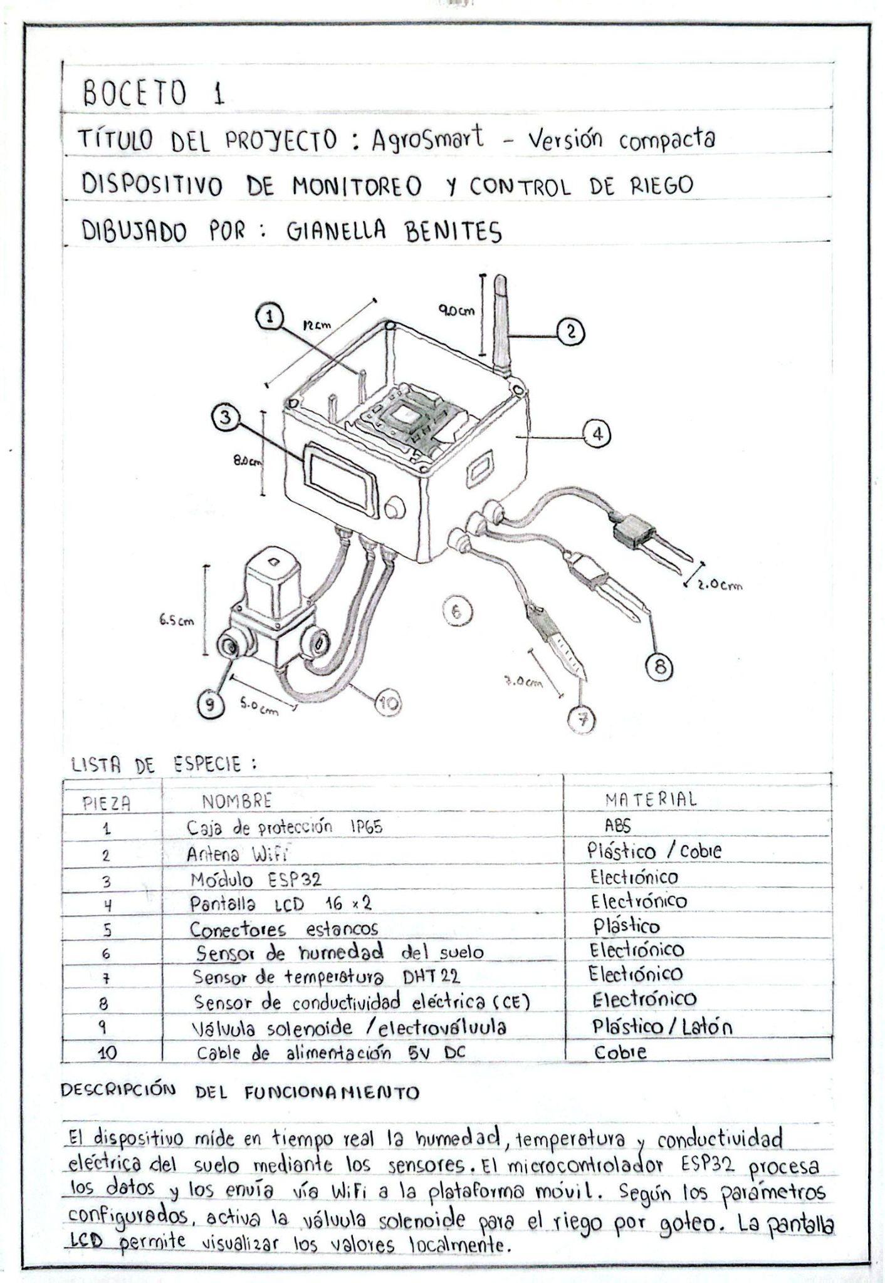
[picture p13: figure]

Página 17

Fundamentos de Diseño

3.2. Boceto 2

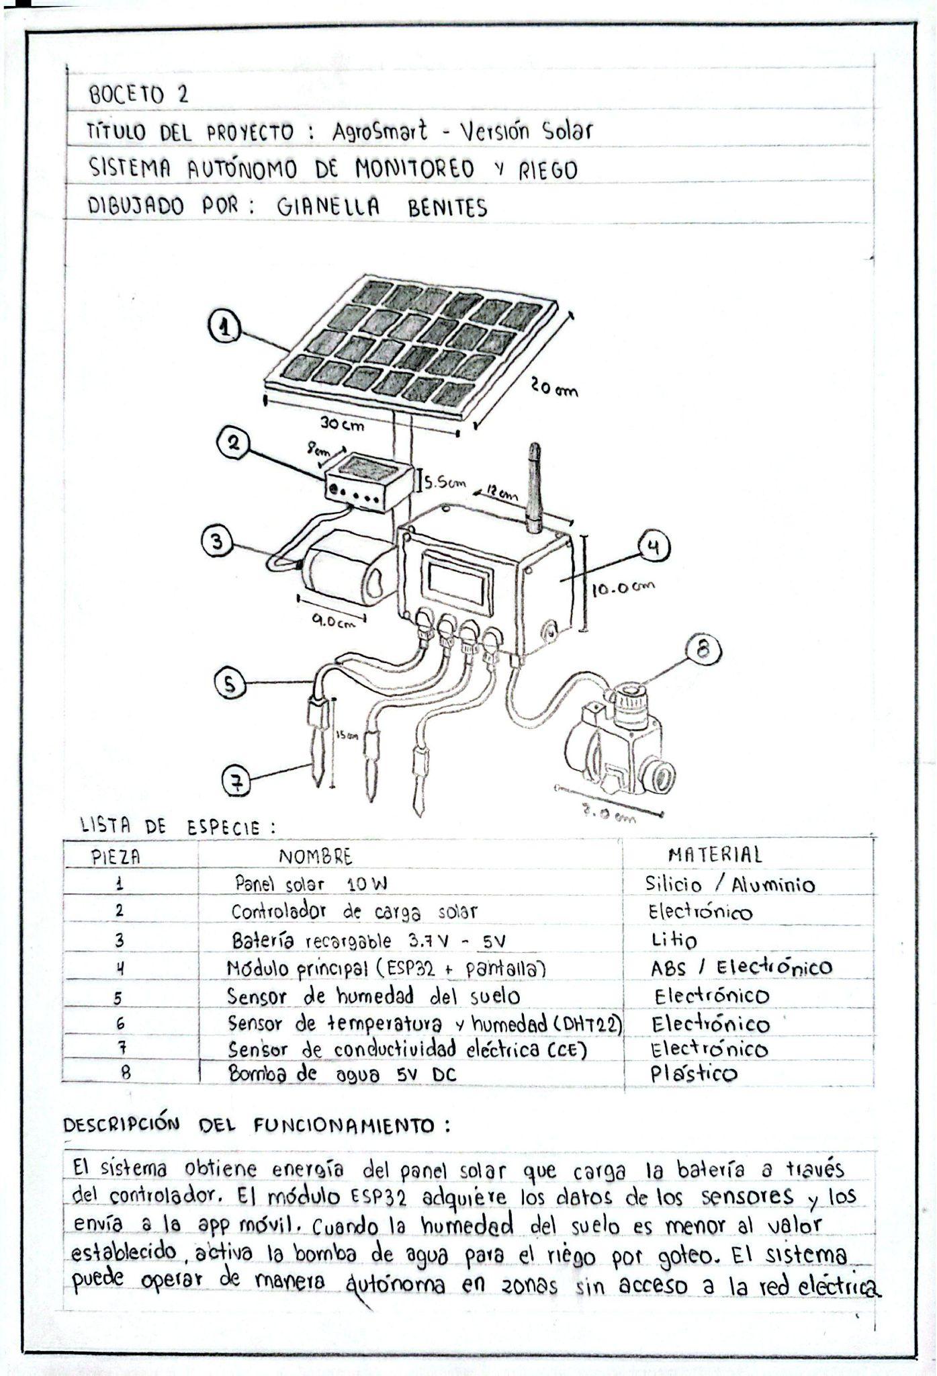
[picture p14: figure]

3.3. Boceto 3

Página 18

Fundamentos de Diseño

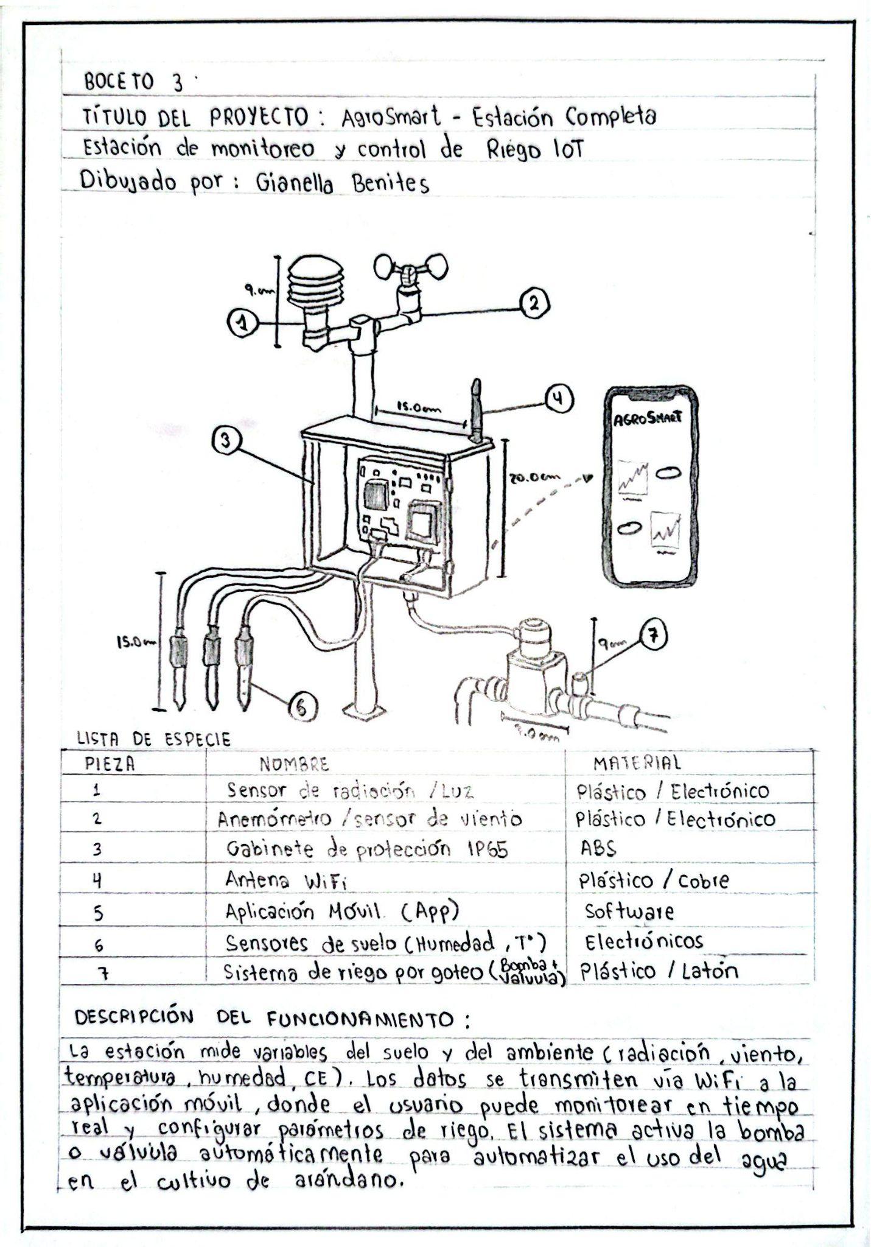
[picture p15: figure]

Página 19

Fundamentos de Diseño

### 4. REFERENCIAS BIBLIOGRÁFICAS

1. (https://www.zotero.org/google-docs/?PXqkTs) ISO [Internet]. [cited 2026 Apr 29]. ISO 46001:2019. Available from: https://www.iso.org/standard/68286.html
2. (https://www.zotero.org/google-docs/?PXqkTs) | a1374s00.pdf | [Internet]. | [cited | 2026 | Apr | 29]. | Available | from:
https://www.fao.org/4/a1374s/a1374s00.pdf
3. (https://www.zotero.org/google-docs/?PXqkTs) Seguridad alimentaria y nutrición [Internet]. [cited 2026 Apr 29]. Available from: https://www.fao.org/agrifood-economics/publications/detail/es/c/1476478/
4. (https://www.zotero.org/google-docs/?PXqkTs) | untitled | [Internet]. | [cited | 2026 | Apr | 29]. | Available | from:
https://agua.org.mx/wp-content/uploads/2014/06/EFICIENCIA_EN_SISTEMAS_DE_RIEGO.pdf
5. (https://www.zotero.org/google-docs/?PXqkTs) Microsoft Word - IrrigSpanish2002.doc [Internet]. [cited 2026 Apr 29]. Available from: https://www.fao.org/4/ak209s/ak209s00.pdf
6. (https://www.zotero.org/google-docs/?PXqkTs) ISO 46001:2019(en), Water efficiency management systems — Requirements with
guidance | for | use | [Internet]. | [cited | 2026 | Apr | 29]. | Available | from:
https://www.iso.org/obp/ui/en/#iso:std:68286:en
7. (https://www.zotero.org/google-docs/?PXqkTs) Ardumania. Qué es el ESP32: características, funcionamiento y cómo aprovecharlo.
Ardumania | [Internet]. | 2025 | Nov | 19 | [cited | 2026 | Apr | 29]. | Available | from:
https://ardumania.es/que-es-el-esp32/
8. (https://www.zotero.org/google-docs/?PXqkTs) Quiroz-Valdez JA, Almaraz-Damian JA, Ramos-Díaz E. Transformación agrícola: implementación de un sistema de Monitoreo IoT para la gestión inteligente de cultivos. Pädi Bol
Científico | Cienc | Básicas | E | Ing | ICBI. | 2024 | Nov | 30;12:188–98.
doi:10.29057/icbi.v12iEspecial4.13323
9. (https://www.zotero.org/google-docs/?PXqkTs) Bernardos JRD de los. Monitoreo continuo y toma de decisiones agronómicas con IoT: hacia la agricultura inteligente. Innovatione [Internet]. 2026 Jan 13 [cited 2026 Apr 29]. Available from: https://innovatione.eu/2026/01/13/iot-agricultura-monitoreo-continuo/
10. (https://www.zotero.org/google-docs/?PXqkTs) NOW RI. IT NOW [Internet]. 2024 [cited 2026 Apr 29]. Protocolo MQTT y su aplicación
en | IOT. | Available | from:
https://www.itnow.connectab2b.com/post/protocolo-mqtt-y-su-aplicacion-en-iot (https://www.zotero.org/google-docs/?PXqkTs)

Página 20

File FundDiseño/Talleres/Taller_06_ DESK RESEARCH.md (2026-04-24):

# MATRIZ DE DESK RESEARCH:

## PROBLEMÁTICA: ¿Cómo diseñar un sistema de riego inteligente de bajo costo que permita optimizar el uso del agua en la agricultura mediante el monitoreo de variables del suelo y ambientales en tiempo real, mejorando la eficiencia hídrica y reduciendo el desperdicio de recursos?

| N° | FUENTE | AUTOR/INSTITUCIÓN | AÑO | REFERENCIA | ESTADO DE TECNOLOGÍA ENCONTRADO | EXISTENCIA O REQUISITO ENCONTRADO | RESTRICCIÓN O LIMITACIÓN | FUNCIÓN PRINCIPAL | APLICACIÓN AL PROYECTO |
| :---: | :---: | :---: | :---: | :---: | :---: | :---: | :---: | :---: | :---: |
| 1 | Norma técnica | Organización Internacional de Normalización (ISO) | 2019 | [https://www.iso.org/standard/68286.html](https://www.iso.org/standard/68286.html) | Sistemas de gestión para la eficiencia en el uso del agua en organizaciones, incluyendo monitoreo, control y mejora continua del consumo hídrico. | Establece requisitos para implementar, mantener y mejorar un sistema de gestión del uso eficiente del agua, incluyendo medición, análisis de consumo y optimización. | Requiere implementación organizacional estructurada, monitoreo constante y recursos técnicos para medición y control del agua. | Optimizar el uso del recurso hídrico mediante gestión eficiente, reducción de desperdicios y mejora continua. | Sirve como base para diseñar un sistema de riego inteligente que monitoree y optimice el uso del agua, alineando el proyecto con estándares internacionales de sostenibilidad. |
| 2 | Manual técnico | FAO | 2006 | [https://www.fao.org/4/a1374s/a1374s00.pdf](https://www.fao.org/4/a1374s/a1374s00.pdf) | Uso de instrumentos y sensores de humedad del suelo, como tensiómetros, para monitorear el contenido de agua y mejorar la programación del riego. | El manual establece que el monitoreo constante del suelo mediante sensores permite determinar cuándo regar y cuánta agua aplicar, siendo clave para una gestión eficiente del riego. | Requiere medición frecuente, interpretación de datos y manejo técnico adecuado para garantizar decisiones correctas en el riego. | Medir la humedad del suelo para optimizar la toma de decisiones en el riego y asegurar un uso eficiente del agua en los cultivos. | Sirve como base técnica para el uso de sensores en AgroAqua Smart, ya que demuestra que el monitoreo de humedad es fundamental para automatizar el riego, optimizar el uso del agua y evitar problemas como la salinización del suelo. |
| 3 | Manual técnico | FAO | 2001 | [https://www.fao.org/4/ak209s/ak209s00.pdf](https://www.fao.org/4/ak209s/ak209s00.pdf) | Sistemas de riego agrícola tradicionales y tecnificados, incluyendo riego por goteo, aspersión y manejo eficiente del agua en cultivos. | Describe criterios técnicos para el diseño, instalación y operación de sistemas de riego, incluyendo control del caudal, frecuencia de riego y necesidades hídricas del suelo. | Los sistemas tradicionales presentan baja automatización y dependen de intervención manual, lo que puede generar ineficiencia en el uso del agua. | Proporcionar lineamientos técnicos para mejorar la eficiencia del riego y optimizar la productividad agrícola. | Sirve como base técnica para definir parámetros de riego (frecuencia, cantidad de agua), que pueden ser automatizados mediante sensores en el sistema propuesto. |
| 4 | Revista INIA Tierra Adentro. | INIA Rayentué | 2010 | [https://agua.org.mx/wp-content/uploads/2014/06/EFICIENCIA\_EN\_SISTEMAS\_DE\_RIEGO.pdf](https://agua.org.mx/wp-content/uploads/2014/06/EFICIENCIA_EN_SISTEMAS_DE_RIEGO.pdf) | Eficiencia en sistemas de riego por goteo en el secano. | Tecnología en uso, evaluada en campo para mejorar su eficiencia. | Requiere buen diseño, presión adecuada, emisores y manejo correcto del riego. | Puede presentar baja eficiencia por mal manejo, problemas de presión y pérdidas de agua. | Mejorar la eficiencia del uso del agua en sistemas de riego por goteo |

##

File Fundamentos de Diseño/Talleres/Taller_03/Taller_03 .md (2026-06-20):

<div align="center">

# Taller 03
 
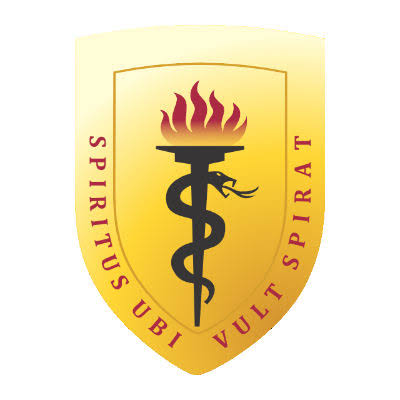
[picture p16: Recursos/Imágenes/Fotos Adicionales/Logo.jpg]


**Trabajo presentado por:**  
Benites Tena, Gianella Yamile  
Delerna Infantes, Anderson Josue  
Landa Torres, Lidia Desairi  
Loayza Pineda, Yenifer  

**Profesores**  
Marco Antonio Mugaburu Celi  
Jose Luiz Da Silva  
Domingo Vladimir Flores Robles Alberto  
Victor Alberto Huanambal Sovero  
Jhomer Rodrigo Contreras Paucca  
Harry Anderson Rivera Tito  
Renzo Jose Chan Rios  
Julissa Elvira Venancio Huerta  
Diana Sheyla Sandoval Eustaquio  
Cristhian Gustavo Jacinto Calderon  

**Universidad Peruano Cayetano Heredia**  
Curso: Fundamentos de Diseño

</div>

--- 

1. **INTRODUCCIÓN:**

   	El uso eficiente del agua en la agricultura constituye uno de los principales desafíos a nivel global, debido a su impacto directo en la sostenibilidad ambiental y la seguridad alimentaria. Actualmente, este sector es el mayor consumidor de recursos hídricos, utilizando aproximadamente el 70% del agua dulce disponible, lo que genera una fuerte presión sobre este recurso, especialmente en contextos de creciente escasez hídrica (1).

   	En el contexto nacional, esta problemática se intensifica en el Perú, particularmente en la costa, donde predominan condiciones climáticas áridas y una limitada disponibilidad de agua. En estas zonas, la producción agrícola depende en gran medida del riego, lo que hace indispensable una gestión eficiente del recurso hídrico. Sin embargo, en la práctica, muchos agricultores aún realizan un riego empírico o “al ojo”, debido a la falta de conocimiento sobre las condiciones del suelo, lo que genera un uso inadecuado del agua y un impacto negativo tanto en el recurso hídrico como en la calidad del suelo.

   	En este escenario, el problema se hace más evidente en zonas agrícolas específicas como Huaral (Lima), donde las condiciones del suelo presentan una alta variabilidad en sus propiedades. Investigaciones realizadas en la Estación Experimental Agraria Donoso evidencian la presencia de suelos con problemas de salinidad, baja materia orgánica y diferencias significativas en su composición (2,3). Estas características dificultan la retención de agua y nutrientes, afectando directamente el crecimiento y desarrollo de los cultivos. Además, esta variabilidad complica la aplicación uniforme del riego, lo que incrementa el riesgo de un uso ineficiente del recurso hídrico. 

   	Las consecuencias de esta problemática son significativas. Una gestión deficiente del riego no solo implica desperdicio de agua, sino que también contribuye a la degradación del suelo, afectando su estructura, fertilidad y capacidad productiva a largo plazo (4). En particular, el exceso de riego puede provocar la acumulación de sales, deteriorando las propiedades del suelo y reduciendo el rendimiento de los cultivos. De manera complementaria, cuando no existe un adecuado sistema de drenaje, el agua aplicada en exceso se evapora y deja sales acumuladas, lo que puede incluso generar la pérdida de cultivos (5).

   	Ante esta situación, resulta fundamental abordar este problema debido a su impacto directo en la sostenibilidad agrícola y en la seguridad alimentaria. La degradación del suelo y el uso ineficiente del agua afectan no solo a los cultivos, sino también a los pequeños y medianos agricultores, quienes dependen de estos recursos para su producción y sustento económico. Asimismo, estas condiciones impactan en la disponibilidad de alimentos y en el equilibrio ambiental, afectando a las comunidades locales y al ecosistema en general (6). Por ello, mejorar la gestión del riego no solo implica un beneficio productivo, sino también social y ambiental.

   	En este contexto, surge la necesidad de implementar soluciones basadas en tecnologías que permitan optimizar el uso del agua mediante un enfoque más preciso. La agricultura de precisión, mediante el uso de sensores y tecnologías de monitoreo, permite mejorar significativamente la eficiencia del riego al adaptar la cantidad de agua a las necesidades específicas del suelo y del cultivo (7). Este enfoque resulta especialmente relevante en zonas con alta variabilidad del suelo, como las presentes en la costa peruana.

   	Además, la incorporación de estas tecnologías en el sector agrícola contribuye a mejorar la competitividad y sostenibilidad, especialmente en regiones con alto estrés hídrico (8). Estas soluciones permiten reducir costos operativos, mejorar el rendimiento de los cultivos y optimizar el uso de recursos, beneficiando directamente a los agricultores y fortaleciendo la seguridad alimentaria. Asimismo, se alinean con los Objetivos de Desarrollo Sostenible, particularmente en lo relacionado con la gestión eficiente del agua y la producción responsable (9). 

   	En consecuencia, el presente proyecto propone el desarrollo de un sistema inteligente de monitoreo aplicado al riego agrícola, el cual permitirá evaluar en tiempo real las condiciones del suelo y optimizar la aplicación del agua. Esta propuesta se caracteriza por integrar tecnologías de sensores y análisis de datos para mejorar la toma de decisiones en el riego, constituyendo una alternativa innovadora orientada a incrementar la eficiencia hídrica, mejorar la calidad del suelo y promover una agricultura más sostenible y resiliente frente al cambio climático.  

2. **REFERENCIAS BIBLIOGRÁFICAS:**

1\.	International Atomic Energy Agency. Gestión del agua con fines agrícolas \[Internet\]. IAEA; 2018 \[cited 2026 Apr 5\]. Available from: http://www.iaea.org/es/temas/gestion-del-agua-con-fines-agricolas 

2\.	Isidoro Ramírez D. Minimización de impactos en la agricultura de regadío \[Internet\]. 2010 \[cited 2026 Apr 5\]. Available from: http://hdl.handle.net/10532/1606 

3\.	Quispe Matos KR, Carbajal Llosa CM, Mejia Maita SY, Chuchon Remon RJ, Quiñones Trejo RA, Samaniego Vivanco TD, et al. Variación espacial de la fertilidad del suelo en la EEA Donoso \[Internet\]. Instituto Nacional de Innovación Agraria (INIA); 2026 \[cited 2026 Apr 5\]. Available from: http://hdl.handle.net/20.500.12955/3064 

4\.	Velasco-Muñoz J, Aznar-Sánchez J, Belmonte-Ureña L, Román-Sánchez I. Sustainable Water Use in Agriculture: A Review of Worldwide Research. Sustainability. 2018 Apr 5;10(4):1084. doi:10.3390/su10041084 

5\.	BID verifica avances de investigación en Estación Experimental Agraria Donoso del INIA – Instituto Nacional de Innovación Agraria \[Internet\]. 2019 Nov 15 \[cited 2026 Apr 5\]. Available from: https://www.inia.gob.pe/2019-nota-140/ 

6\.	FAO. Water for sustainable food and agriculture \[Internet\]. FAO; 2016 \[cited 2026 Apr 7\]. p. 33\. Available from: https://openknowledge.fao.org/handle/20.500.14283/i7959en 

7\.	Shamshiri RR, Balasundram SK, Rad AK, Sultan M, Hameed IA. An Overview of Soil Moisture and Salinity Sensors for Digital Agriculture Applications. In: Digital Agriculture, Methods and Applications \[Internet\]. IntechOpen; 2022 \[cited 2026 Apr 5\]. Available from: https://www.intechopen.com/chapters/82324 doi:10.5772/intechopen.103898 

8\.	Avila JZ. Reporte Electrónico Tecnológico (RET): Sistemas y equipos inteligentes de aplicación en la Agricultura \[Internet\]. 2022\. Available from: https://www.patenta.pe/wp-content/uploads/2025/05/RET-Agricultura.pdf 

9\.	ONU. Objetivos y metas de desarrollo sostenible. Desarrollo Sostenible \[Internet\]. \[cited 2026 Apr 5\]. Available from: https://www.un.org/sustainabledevelopment/es/sustainable-development-goals/ 

[image1]: <>

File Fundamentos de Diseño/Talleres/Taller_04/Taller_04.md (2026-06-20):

<div align="center">

# Taller 04
 


**Trabajo presentado por:**  
Benites Tena, Gianella Yamile  
Delerna Infantes, Anderson Josue  
Landa Torres, Lidia Desairi  
Loayza Pineda, Yenifer  
Pellane Aro, Carlos Alfredo

**Profesores**  
Marco Antonio Mugaburu Celi  
Jose Luiz Da Silva  
Domingo Vladimir Flores Robles Alberto  
Victor Alberto Huanambal Sovero  
Jhomer Rodrigo Contreras Paucca  
Harry Anderson Rivera Tito  
Renzo Jose Chan Rios  
Julissa Elvira Venancio Huerta  
Diana Sheyla Sandoval Eustaquio  
Cristhian Gustavo Jacinto Calderon  

**Universidad Peruano Cayetano Heredia**  
Curso: Fundamentos de Diseño

</div>

--- 

# **PATENTES RELACIONADAS CON NUESTRO PROYECTO**

---

## **PATENTE 1**

| CAMPO | INFORMACIÓN |
| :---- | :---- |
| TÍTULO | DISPOSITIVO DE RIEGO AUTOMÁTICO CON CONTROL DE HUMEDAD, PH Y TEMPERATURA |
| N° PUBLICACIÓN | PE2026-0366 |
| CIP | [A01G 25/16](https://www.wipo.int/ipcpub/?symbol=A01G0025160000&menulang=es&lang=es) |

| RESUMEN | IMÁGENES |
| :---- | :---- |
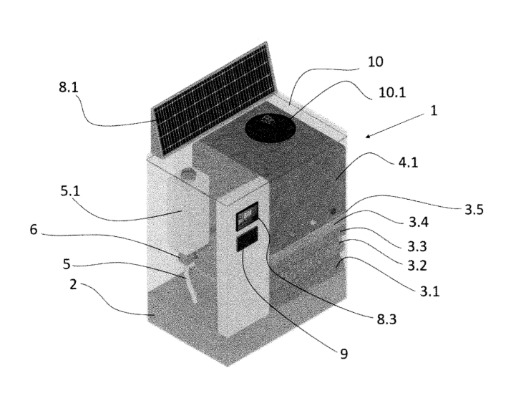
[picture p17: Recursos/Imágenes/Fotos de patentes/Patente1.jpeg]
| La invención describe un dispositivo de riego automático que regula la humedad, pH y temperatura del suelo para optimizar el suministro de agua en cultivos. Cuenta con un depósito de agua, un medio capilar que facilita la ascensión de agua, y sensores que monitorean el suelo. Un microcontrolador procesa los datos y acciona válvulas según los umbrales definidos, manteniendo el equilibrio hídrico en la zona radicular. Funciona con energía solar mediante panel, batería y controlador, permitiendo operación autónoma. Incluye una tapa tipo lisímetro, módulos de visualización y comunicación para monitoreo local y remoto. El sistema mejora la eficiencia del riego, reduce pérdidas de agua y mantiene condiciones físico-químicas estables, siendo útil en agricultura y experimentación con mínima intervención. |   |

🔗[Ver Patente](https://patentscope.wipo.int/search/es/detail.jsf?docId=PE475409654&_cid=P21-MNPAPG-97696-1)

---

## **PATENTE 2**

| CAMPO | INFORMACIÓN |
| :---- | :---- |
| TÍTULO | SISTEMA DE RIEGO, SENSOR DE RIEGO Y PROGRAMACIÓN INTELIGENTE PARA EL RIEGO, PROCESOS Y MÉTODOS DE USO. |
| N° PUBLICACIÓN | US 2025/0048979  |
| CIP | A01G25/167 |

| RESUMEN | IMÁGENES |
| :---- | :---- |
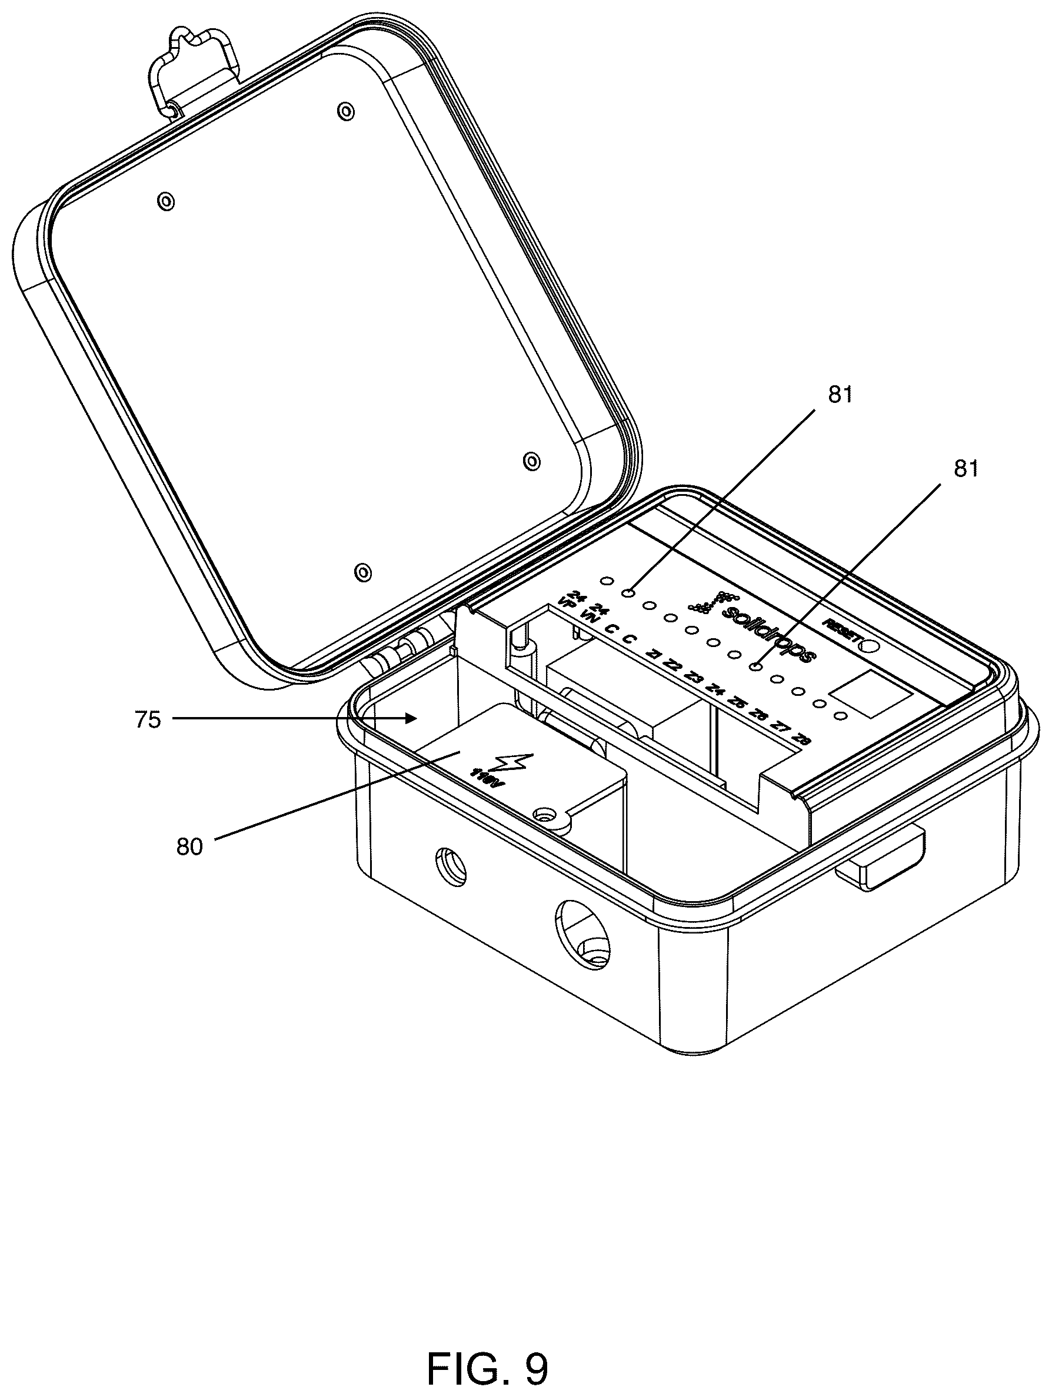
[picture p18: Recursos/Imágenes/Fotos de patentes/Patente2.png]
| El sistema presentado describe una solución inteligente de riego que integra sensores inalámbricos de humedad del suelo y controladores automatizados para optimizar el uso del agua. Este sistema incorpora un módulo de programación inteligente que, mediante reglas predefinidas y aprendizaje automático continuo, ajusta las condiciones de riego según las necesidades del suelo. Además, utiliza inteligencia artificial para mejorar la toma de decisiones, permitiendo un riego automatizado y eficiente. Su diseño busca reducir el consumo de agua, energía y tiempo, generando beneficios tanto para el usuario como para el entorno en general. |   |

🔗[Ver Patente](https://patents.google.com/patent/US20250048979A1/en)

---

**PATENTE 3**

| CAMPO | INFORMACIÓN |
| :---- | :---- |
| TÍTULO | SISTEMA DE RIEGO POR GOTEO ALINEADO FIJO. |
| N° PUBLICACIÓN | ES2 351 902 |
| CIP | [A01G25/02](https://es.espacenet.com/publicationDetails/biblio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) |

| RESUMEN | IMÁGENES |
| :---- | :---- |
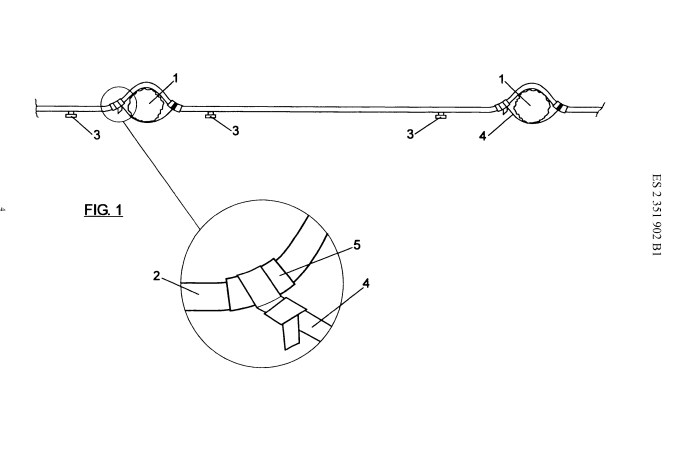
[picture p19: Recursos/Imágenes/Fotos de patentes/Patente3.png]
| El sistema describe un mecanismo de riego por goteo alineado fijo que utiliza una manguera equipada con goteros dispuestos alrededor de árboles o plantas. Este sistema incorpora un medio de sujeción conectado a abrazaderas instaladas en la manguera, lo que permite ajustar y asegurar su posición. Además, su diseño posibilita el giro de la manguera alrededor de la planta sin provocar estrangulamientos, garantizando una distribución uniforme del agua. Su objetivo es mejorar la eficiencia del riego localizado y facilitar su adaptación a diferentes tipos de cultivos. |   |

🔗[Ver Patente](https://es.espacenet.com/publicationDetails/biblio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)

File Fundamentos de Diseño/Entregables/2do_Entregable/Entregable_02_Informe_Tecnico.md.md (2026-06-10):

# Entregable 2 – Avance del Informe del Proyecto

<p align="center">
  <a href="https://github.com/SharkUsser/FdD_Equipo01/blob/main/FundDise%C3%B1o/Entregables/2do_Entregable%20trabajado/Entregable_02%20Informe%20T%C3%A9cnico.pdf">
    
  </a>
</p>

## Descripción

En este entregable se presenta el avance del informe correspondiente al desarrollo del proyecto. El documento recopila las actividades realizadas durante las primeras etapas del proceso de diseño, incluyendo la identificación de la necesidad, el análisis de antecedentes, la generación de alternativas de solución y la selección del boceto conceptual que servirá como base para el desarrollo posterior del proyecto.

## Contenido del Entregable

El informe incluye los siguientes aspectos:

- Definición del problema y necesidad identificada.
- Investigación de antecedentes y estado del arte.
- Análisis de patentes y soluciones existentes relacionadas con el proyecto.
- Identificación de requerimientos y restricciones de diseño.
- Desarrollo de la matriz morfológica y generación de conceptos.
- Evaluación y comparación de alternativas propuestas.
- Selección del boceto final mediante criterios de evaluación técnica y funcional.
- Descripción preliminar de la solución elegida.

## Objetivo

Presentar el progreso alcanzado en la fase conceptual del proyecto y justificar la selección del boceto que será utilizado como base para las siguientes etapas de diseño, modelado CAD y prototipado.

## Evidencia del Entregable

El informe técnico correspondiente al segundo entregable puede consultarse en el siguiente enlace:

📄 **[Ver Informe Técnico](https://github.com/SharkUsser/FdD_Equipo01/blob/main/FundDise%C3%B1o/Entregables/2do_Entregable%20trabajado/Entregable_02%20Informe%20T%C3%A9cnico.pdf)**

## Archivos Relacionados

- Informe de avance del proyecto.
- Boceto seleccionado.
- Evidencias del proceso de evaluación de alternativas.

## Estado del Proyecto

✅ Fase conceptual completada.

🔄 Próxima etapa: desarrollo detallado del diseño, modelado CAD y construcción del prototipo.

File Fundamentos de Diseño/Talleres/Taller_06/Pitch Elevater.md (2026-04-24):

## 🚀 Presentación del Proyecto

<p align="center">
  <a href="https://docs.google.com/document/d/1F-rUtN4siC1MLgj3hYKBEHAPO4A_dc9dfYv1meuLcQw/edit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" target="_blank">
    
  </a>
  <a href="https://canva.link/7gyr0cctpvljlwa" target="_blank">
    
  </a>
</p>

<p align="center">
  Accede al documento técnico y a la presentación del proyecto AGRO SMART.
</p>

# **AGRO SMART** **optimización inteligente del riego agrícola**

## **1\. Historia**

En el Perú, país reconocido por su crecimiento en agroexportación, la agricultura se ha convertido en un pilar clave de la economía.

Este sector no solo genera empleo, sino que impulsa el desarrollo del país y fortalece su presencia en mercados internacionales.

Sin embargo, ante este crecimiento, surge una pregunta importante:  
**¿realmente estamos utilizando bien nuestros recursos para sostenerlo?**

Porque crecer no solo es producir más, sino hacerlo de manera eficiente y sostenible.

--- 

## **2\. Problema**

A pesar de contar con sistemas como riego por gravedad, aspersión y goteo, el uso del agua aún no es completamente eficiente.

* A nivel global, la agricultura consume cerca del **70% del agua dulce disponible**  
* Gran parte de este recurso se desperdicia por un manejo inadecuado

Esto genera consecuencias como:

* Salinización del suelo  
* Reducción de la productividad  
* Deterioro de la calidad del terreno

Además:

* El riego suele basarse en intuición  
* Falta acceso a herramientas de monitoreo  
* No se toman decisiones basadas en datos

**Problema central:**  
Uso ineficiente del agua debido a la falta de control y monitoreo en tiempo real del suelo y cultivo.

---

## **3\. Solución**

Proponemos **Agro Smart (AS)**, un sistema inteligente que:

* Monitorea la salud del suelo y del cultivo en tiempo real  
* Utiliza sensores de:  
  * Humedad  
  * pH  
  * Conductividad

Permite detectar:

* Salinidad  
* Estrés hídrico

Además:

* Integra riego por goteo automatizado  
* Aplica solo la cantidad de agua necesaria

💡 Ejemplo:  
 Un agricultor puede revisar desde su celular el estado del suelo y recibir recomendaciones precisas sobre cuándo regar.

✔ Resultado:

* Optimización del uso del agua  
* Protección del suelo  
* Mayor productividad agrícola

---

## **4\. Modelo de negocio**

Agro Smart combina:

* Venta del sistema  
* Suscripción a una app inteligente

La plataforma permite:

* Monitoreo en tiempo real  
* Recomendaciones automatizadas

💡 Beneficio:

* Ingresos recurrentes  
* Servicio continuo

✔ Enfoque:  
 No solo vendemos un producto, sino una **solución tecnológica escalable y sostenible**.

---

## **5\. Estrategia**

1. Implementación inicial en zonas agrícolas  
2. Validación en campo con agricultores  
3. Demostraciones con resultados reales  
4. Generación de confianza y adopción

Posteriormente:

* Alianzas con actores del sector agrícola  
* Expansión progresiva

🎯 Objetivo:  
 Escalar el sistema con alto impacto y bajo costo de adopción.

---

## **6\. Tracción**

Resultados obtenidos:

* Reducción de hasta **30% en el uso de agua**  
* Detección temprana de:  
  * Salinidad  
  * Estrés hídrico  
* Más del **95% de precisión** en detección de plagas

✔ Impacto:

* Menores costos  
* Mayor productividad  
* Agricultura más sostenible

---

## **7\. Equipo**

Somos un equipo de estudiantes de ingeniería comprometidos con la innovación y sostenibilidad agrícola.

Contamos con conocimientos en:

* Gestión del agua  
* Tecnologías aplicadas  
* Soluciones inteligentes

✔ Enfoque:  
 Desarrollar soluciones prácticas, basadas en investigación, con impacto real en el sector agrícola.

---

## **8\. Propuesta de valor**

Agro Smart no es solo un sistema de riego, es una solución integral que combina:

* Monitoreo en tiempo real  
* Automatización del riego  
* Toma de decisiones basada en datos

Beneficios:

* Uso eficiente del agua  
* Mejora del suelo  
* Incremento de productividad

✔ Diferencial:  
 Transformamos el riego tradicional en un proceso **inteligente, preciso y sostenible**.

---

## **9\. Impacto**

Agro Smart contribuye a:

* Optimizar el uso del agua a nivel agrícola  
* Reducir la degradación del suelo  
* Mejorar la sostenibilidad del sector

🌱 En un contexto donde el agua es un recurso cada vez más limitado, nuestra solución busca asegurar un crecimiento agrícola responsable.

---

# **📚 Referencias** 

1. Food and Agriculture Organization of the United Nations. *Water use in agriculture* \[Internet\]. Rome: FAO; 2020 \[citado 2026 Abr 23\]. Disponible en: [https://www.fao.org/aquastat/en/overview/methodology/water-use](https://www.fao.org/aquastat/en/overview/methodology/water-use)  
2. World Bank. *Water in agriculture* \[Internet\]. Washington (DC): World Bank; 2022 \[citado 2026 Abr 23\]. Disponible en: [https://www.worldbank.org/en/topic/water-in-agriculture](https://www.worldbank.org/en/topic/water-in-agriculture)  
3. Food and Agriculture Organization of the United Nations. *Status of the World’s Soil Resources* \[Internet\]. Rome: FAO; 2015 \[citado 2026 Abr 23\]. Disponible en: [https://www.fao.org/3/i5199e/i5199e.pdf](https://www.fao.org/3/i5199e/i5199e.pdf)

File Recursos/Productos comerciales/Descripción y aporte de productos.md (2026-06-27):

# Productos Comerciales

## Descripción

En esta sección se presentan los productos comerciales analizados durante el desarrollo del proyecto. Estos productos fueron seleccionados por incorporar tecnologías y características relacionadas con el monitoreo agrícola, automatización del riego y gestión eficiente de recursos, sirviendo como referencia para la definición de funcionalidades y componentes del prototipo.

<p align="center">
    <a href="https://github.com/SharkUsser/FdD_Equipo01/blob/main/Recursos/Productos%20comerciales/Brochure%20Producto_01%20Hydrawise.pdf">
     
    </a>
    <a href="https://github.com/SharkUsser/FdD_Equipo01/blob/main/Recursos/Productos%20comerciales/Brochure%20Producto_02%20Netafim.pdf">
     
    </a>
    <a href="https://github.com/SharkUsser/FdD_Equipo01/blob/main/Recursos/Productos%20comerciales/Brochure%20Producto_03%20Tecfresh%20MeterGroup.pdf">
     
    </a>
    <a href="https://github.com/SharkUsser/FdD_Equipo01/blob/main/Recursos/Productos%20comerciales/Brochure%20Producto_04%20Vegetronix.pdf">
     
    </a>
</p>

---

# Producto 1

### Nombre del Producto

### **Hydrawise – Sistema Inteligente de Gestión de Riego**

### Descripción

Hydrawise es una plataforma inteligente de control de riego desarrollada por Hunter Industries que permite gestionar sistemas de riego de manera remota mediante conexión Wi-Fi. El sistema utiliza datos meteorológicos en tiempo real para ajustar automáticamente los programas de riego según las condiciones climáticas locales, optimizando el consumo de agua. Además, incorpora monitoreo de caudal, generación de alertas, administración de múltiples sitios y acceso remoto desde dispositivos móviles y computadoras. 

### Aporte al Proyecto

- Sirvió como referencia para implementar el monitoreo y control remoto del sistema de riego.
- Sustentó la importancia de utilizar información ambiental para optimizar el uso del agua.
- Inspiró la incorporación de alertas y supervisión del estado del sistema para detectar posibles fallas.
- Proporcionó criterios de diseño orientados a la automatización y eficiencia hídrica.
- Reforzó la necesidad de una interfaz que permita al usuario consultar información del sistema de forma sencilla. 

📄 [Ver brochure](https://github.com/SharkUsser/FdD_Equipo01/blob/main/Recursos/Productos%20comerciales/Brochure%20Producto_01%20Hydrawise.pdf)

---

# Producto 2

### Nombre del Producto

### **Netafim – Soluciones de Riego de Precisión**

### Descripción

Netafim ofrece una amplia gama de tecnologías para riego de precisión, incluyendo válvulas de control, filtros, sistemas de filtración, tuberías, conectores y soluciones de automatización. Sus productos están diseñados para optimizar la distribución del agua, regular la presión, proteger los sistemas hidráulicos y mejorar la eficiencia del riego en aplicaciones agrícolas.

### Aporte al Proyecto

- Sirvió como referencia para el diseño del sistema de distribución de agua.
- Permitió identificar componentes necesarios para el control del caudal y la presión.
- Proporcionó criterios para la selección de elementos hidráulicos aplicables al prototipo.
- Evidenció la importancia de la filtración para evitar obstrucciones en sistemas de riego.
- Ayudó a comprender la integración de válvulas y accesorios en sistemas agrícolas automatizados.

📄 [Ver brochure](https://github.com/SharkUsser/FdD_Equipo01/blob/main/Recursos/Productos%20comerciales/Brochure%20Producto_02%20Netafim.pdf)

---

# Producto 3

### Nombre del Producto

### **METER Group ZL6 – Registrador de Datos Inalámbrico**

### Descripción

El ZL6 es un datalogger inalámbrico diseñado para la adquisición, almacenamiento y gestión remota de datos ambientales y agrícolas. Cuenta con conectividad Bluetooth, GPS integrado, almacenamiento en la nube mediante ZENTRA Cloud y capacidad para conectar múltiples sensores de humedad del suelo y variables climáticas. Además, incorpora alimentación mediante energía solar y monitoreo en tiempo real.

### Aporte al Proyecto

- Sirvió como referencia para la gestión y almacenamiento de datos de sensores.
- Sustentó la importancia del monitoreo remoto mediante plataformas digitales.
- Inspiró la integración de sistemas de comunicación para supervisar variables agrícolas.
- Proporcionó criterios para la visualización y análisis de datos en tiempo real.
- Reforzó la necesidad de registrar información histórica para la toma de decisiones.

📄 [Ver brochure](https://github.com/SharkUsser/FdD_Equipo01/blob/main/Recursos/Productos%20comerciales/Brochure%20Producto_03%20Tecfresh%20MeterGroup.pdf)

---

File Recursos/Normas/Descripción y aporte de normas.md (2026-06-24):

# Normas

## Descripción

En esta sección se presentan las normas técnicas consideradas durante el desarrollo del proyecto. Estas normas proporcionan lineamientos y criterios de diseño relacionados con la eficiencia en el uso del agua, la automatización de sistemas y las buenas prácticas de ingeniería, contribuyendo al desarrollo de una solución funcional y sostenible.

<p align="center">
    <a href="https://github.com/SharkUsser/FdD_Equipo01/blob/main/Recursos/Normas/NormaT%C3%A9cnica_1.pdf">
      
    </a>
    <a href="https://github.com/SharkUsser/FdD_Equipo01/blob/main/Recursos/Normas/NormaT%C3%A9cnica_2.pdf">
      
    </a>
    <a href="https://github.com/SharkUsser/FdD_Equipo01/blob/main/Recursos/Normas/NormaT%C3%A9cnica_3.pdf">
      
    </a>
</P>

---

# Norma Técnica 1

### Nombre de la Norma

### **IEC 60529 - Grados de Protección**

### Descripción

Esta norma internacional de la IEC establece un sistema estandarizado para clasificar el nivel de protección que ofrece una envolvente (carcasa/gabinete) de equipo eléctrico frente a dos amenazas: ingreso de cuerpos sólidos extraños (incluido el polvo) e ingreso de agua. La clasificación se expresa con el código IP seguido de dos dígitos característicos — el primero va del 0 al 6 e indica protección contra sólidos y acceso a partes peligrosas, el segundo va del 0 al 8 e indica el nivel de protección contra agua (desde goteo vertical hasta inmersión continua). Adicionalmente, la norma contempla letras opcionales para protección adicional y letras suplementarias para información complementaria. Cada nivel de clasificación tiene pruebas físicas estandarizadas que deben superarse para certificar el grado declarado.

### Aporte al Proyecto

- Selección del grado IP del gabinete: Al operar en campo abierto en Huaral, el enclosure impreso en PETG está expuesto a polvo agrícola y salpicaduras del riego. La norma justifica técnicamente apuntar a un mínimo de IP54 (protección total contra polvo + salpicaduras desde cualquier dirección) o IP65 si se busca hermeticidad completa.
- Decisiones de diseño del enclosure: Respalda elecciones como el uso de juntas de sellado en la tapa, el posicionamiento correcto de las entradas de cables y el tipo de cierre, asegurando que el gabinete cumpla el grado IP declarado.
- Justificación técnica ante evaluadores: Permite argumentar con respaldo normativo por qué el gabinete tiene las características físicas que tiene, en lugar de decidirlo de manera empírica.

📄 [Ver norma](https://github.com/SharkUsser/FdD_Equipo01/blob/main/Recursos/Normas/NormaT%C3%A9cnica_1.pdf)

---

# Norma Técnica 2

### Nombre de la Norma

### **ISO 46001:2019: Sistemas de gestión de la Eficiencia del Agua**

### Descripción

Esta norma ISO establece los requisitos y orientaciones para que cualquier organización — independientemente de su tamaño o sector — implemente, mantenga y mejore un Sistema de Gestión de la Eficiencia Hídrica (SGEH). Sigue la estructura del ciclo PDCA (Planificar–Hacer–Verificar–Actuar) y exige que la organización realice una revisión del uso del agua, identifique actividades de uso significativo, defina indicadores de actividad empresarial (BAI) e indicadores de eficiencia hídrica (WEI), establezca líneas base, fije objetivos y planes de acción, y realice seguimiento y auditoría periódica. La norma también contempla el enfoque de las 3R aplicado al agua: reducir, reemplazar y reutilizar, y reconoce fuentes alternativas como agua recuperada, aguas grises y agua de lluvia.

### Aporte al Proyecto

- Fundamentación del propósito del proyecto: El cultivo de arándanos requiere precisión hídrica para evitar estrés o exceso de agua. La norma respalda formalmente que monitorear y controlar el riego no es solo una decisión práctica, sino una necesidad alineada con estándares internacionales de eficiencia hídrica.
- Validación de los sensores utilizados: El sensor FC-28 (humedad del suelo) y el sensor TDS (conductividad del agua) responden directamente a la exigencia de la norma de medir el uso actual del agua e identificar actividades de uso significativo, tal como establece su cláusula 6.2.4.
- Base para indicadores de rendimiento: Los datos recolectados por el ESP32 permiten calcular indicadores como m³ de agua por kg de arándano producido, lo cual se alinea con la cláusula 6.2.6 que exige definir indicadores de eficiencia hídrica medibles.
- Justificación de la automatización del riego: La activación automática del relay para abrir o cerrar la electroválvula según los umbrales del sensor responde al requisito de la cláusula 8.1 sobre implementar controles operacionales sobre los usos significativos del agua.

📄 [Ver norma](https://github.com/SharkUsser/FdD_Equipo01/blob/main/Recursos/Normas/NormaT%C3%A9cnica_2.pdf)

---

# Norma Térnica 3

### Nombre de la Norma

### **ISO 16484-1:2024: Sistemas de automatización y control de edificios (BACS) — Parte 1: Especificación e implementación de proyectos**

### Descripción

Esta norma ISO define los principios guía y las fases que debe seguir cualquier proyecto de sistema de automatización y control, estructurándolo en cuatro etapas secuenciales: fase de diseño (determinación de requisitos, planificación, especificación técnica y contrato), fase de ingeniería (diseño detallado de hardware y funciones, configuración de estrategias de control y pruebas del sistema), fase de instalación (montaje físico y puesta en marcha/commissioning) y fase de finalización (demostración del sistema, formación al operador, entrega formal, aceptación y cierre del proyecto). También exige documentación as-built y establece que la calidad del sistema depende directamente de la rigurosidad en el diseño y en el proceso de commissioning.

### Aporte al Proyecto

- Estructura metodológica del proyecto: Aunque fue concebida para edificios, sus cuatro fases se aplicaron directamente a AgroSmart: la fase de diseño corresponde a la Lista de Exigencias y especificación del hardware; la fase de ingeniería al diseño del esquemático en EasyEDA y programación del firmware; la fase de instalación al montaje del PCB en el gabinete 3D; y la fase de finalización a la exposición y entrega de documentación.
- Exigencia de documentación técnica: La norma requiere documentación as-built del sistema, lo que respalda la generación de los documentos técnicos de AgroSmart (esquemático, lista de componentes, memoria descriptiva del enclosure) bajo versiones V1.0 hasta VFINAL.
- Validación del proceso de commissioning: La norma establece que el sistema debe probarse antes de la entrega formal, lo que justifica las pruebas de funcionamiento del circuito (verificación de sensores, relay y pantalla LCD) previas a la exposición final del proyecto.
- Respaldo normativo a la integración de subsistemas: La norma reconoce que un sistema de automatización integra múltiples subsistemas (sensores, actuadores, interfaz de usuario), validando la arquitectura de AgroSmart que combina ESP32, sensores, relay, LCD y módulo de energía solar en un solo sistema funcional.

📄 [Ver norma](https://github.com/SharkUsser/FdD_Equipo01/blob/main/Recursos/Normas/NormaT%C3%A9cnica_3.pdf)

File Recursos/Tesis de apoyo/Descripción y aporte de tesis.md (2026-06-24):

# Tesis

## Descripción

En esta sección se presentan las tesis consultadas como antecedentes para el desarrollo del proyecto. Estos trabajos de investigación proporcionan información técnica y metodológica relacionada con sistemas de riego inteligente, monitoreo de variables agrícolas y automatización de procesos, contribuyendo a la fundamentación y mejora del diseño propuesto.

<p align="center">
    <a href="https://github.com/SharkUsser/FdD_Equipo01/blob/main/Recursos/Tesis%20de%20apoyo/Tesis_01.pdf">
     
    </a>
    <a href="https://github.com/SharkUsser/FdD_Equipo01/blob/main/Recursos/Tesis%20de%20apoyo/Tesis_02.pdf">
     
    </a>
</p>

---

# Tesis 1

### Título

### **Diseño de un sistema automatizado de riego por goteo. Un caso de estudio en un vivero de cultivo de arándano.**
*Asencio, D. y Romero, K. (2023)*   
*Tesis de pregrado, Universidad Privada del Norte*

### Descripción

La investigación se centró en el diseño de un sistema de riego automatizado por goteo enfocado en la optimización del uso del agua dentro de un vivero de arándanos. Utilizó una placa Arduino UNO conectada a sensores FC-28 (humedad de suelo) y DHT11 (temperatura del aire) para monitorear las condiciones ambientales, complementando el diseño técnico mediante simulaciones hidráulicas y electrónicas en Proteus y modelado 3D en SketchUp.

### Aporte al Proyecto

- Configuración de variables de control: Brinda los parámetros óptimos de operación (humedad de suelo entre 40% y 50%, y umbrales de temperatura de $25^\circ\text{C}$) para la automatización del algoritmo.  
- Arquitectura de hardware de bajo costo: Valida la viabilidad técnica y económica de utilizar microcontroladores libres y sensores comerciales de bajo coste para entornos de cultivo controlados.  
- Metodología de simulación previa: Aporta un marco de diseño digital estructurado que permite validar la lógica de programación y el circuito eléctrico antes de la implementación física, reduciendo riesgos de fallo. 

📄 [Ver tesis completa](https://github.com/SharkUsser/FdD_Equipo01/blob/main/Recursos/Tesis%20de%20apoyo/Tesis_01.pdf)

---

# Tesis 2

### Título

### **Evaluación del sistema de tratamiento de agua de riego del cultivo de arándano (Vaccinium corymbosium) en el proyecto Olmos - Lambayeque.**
*Custodio, D. (2025)*   
*Trabajo de suficiencia profesional, Universidad Nacional Agraria La Molina*

### Descripción

La investigación evalúa y analiza el funcionamiento de una planta de tratamiento de agua destinada exclusivamente al riego de grandes extensiones de arándanos. Se enfoca en resolver problemas de obstrucción en los sistemas de goteo mediante procesos hidráulicos de filtrado y control de sólidos suspendidos para garantizar la calidad del agua que llega a la raíz.

### Aporte al Proyecto

- Prevención de obstrucciones hidráulicas: Aporta criterios técnicos sobre el manejo de sedimentos y sólidos para evitar que las impurezas tapen las electroválvulas y goteros de nuestro prototipo.
- Control de calidad del agua para arándanos: Detalla los requerimientos físicos del agua (como la turbidez y el manejo de flujos) específicos para el cultivo de arándano, sirviendo de base para justificar el diseño de nuestra red de distribución.

📄 [Ver tesis completa](https://github.com/SharkUsser/FdD_Equipo01/blob/main/Recursos/Tesis%20de%20apoyo/Tesis_02.pdf)

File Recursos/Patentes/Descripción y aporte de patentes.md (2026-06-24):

# Patentes

## Descripción

En esta sección se presentan las patentes analizadas como referencia para el desarrollo del proyecto. Cada patente aporta soluciones tecnológicas relacionadas con sistemas de riego, automatización, monitoreo de variables agrícolas y optimización del uso de recursos hídricos, permitiendo identificar características y funcionalidades relevantes para el diseño del prototipo.

<p align="center">
    <a href="https://github.com/SharkUsser/FdD_Equipo01/blob/main/Recursos/Patentes/US20250048979A1.pdf">
     
    </a>
    <a href="https://github.com/SharkUsser/FdD_Equipo01/blob/main/Recursos/Patentes/PE20260366A1.pdf">
    
    </a>
    <a href="https://github.com/SharkUsser/FdD_Equipo01/blob/main/Recursos/Patentes/CN201674848U.pdf">
    
    </a>
    <a href="https://github.com/SharkUsser/FdD_Equipo01/blob/main/Recursos/Patentes/ES2351902A1.pdf">
     
    </a>
</p>

---

# Patente 1

### Título

### **US20250048979A1: Irrigation System, Irrigation Sensor and Smart Scheduling for Irrigation, Processes, and Methods of Use**
*US20250048979A1: Sistema de riego, sensor de riego y programación inteligente para riego, procesos y métodos de uso*

### Descripción

Es un sistema de riego automatizado que utiliza sensores de humedad multinivel (estacas que miden la tierra a diferentes profundidades), controladores de válvulas y repetidores de señal para optimizar el uso del agua. El núcleo del invento es un software con Inteligencia Artificial y Machine Learning que analiza los datos del suelo, el clima actual y el pronóstico meteorológico para recalcular y reprogramar automáticamente los horarios de riego en tiempo real, evitando el desperdicio.

### Aporte al Proyecto: *¿Qué valor da al desarrollo del proyecto?*

- Monitoreo vertical real: En lugar de medir solo la superficie, su diseño de varilla permite saber cuánta agua hay exactamente a la altura de las raíces, evitando ahogar la planta o dejarla seca.  
- Riego dinámico por IA: Reemplaza los temporizadores fijos tradicionales por un algoritmo que "aprende" y adapta el riego según el clima y el tipo de suelo.  
- Arquitectura inalámbrica escalable: Estructura un modelo claro de comunicación ideal para diseñar sistemas automáticos en campos grandes.  
- Eficiencia energética de larga duración: Su diseño electrónico está optimizado para que los sensores remotos operen con baterías durante varios años sin mantenimiento constante. 

📄 [Ver patente completa](https://github.com/SharkUsser/FdD_Equipo01/blob/main/Recursos/Patentes/US20250048979A1.pdf)

---

# Patente 2

### Título

### **PE20260366A1: Dispositivo de Riego Automático con Control de Humedad, pH y Temperatura**

### Descripción

El invento consiste en un dispositivo electrónico-mecánico de riego automatizado e inteligente diseñado para optimizar el uso del agua en la agricultura. El sistema opera mediante un bloque de captación con sensores que miden continuamente la humedad, la temperatura y el pH del suelo, enviando estos datos físico-químicos en tiempo real a un microcontrolador central. Este componente procesa la información y ejecuta un algoritmo programado para activar de forma autónoma bombas o electroválvulas de riego solo cuando las variables salen de los rangos ideales del cultivo. Finalmente, el dispositivo cuenta con un módulo de comunicación inalámbrica que transmite todas las métricas recolectadas a una aplicación móvil, permitiendo al usuario monitorear e interactuar con el estado del suelo de manera remota.

### Aporte al Proyecto
Este antecedente técnico aporta directamente a nuestro desarrollo en los siguientes puntos:
- Validación del Hardware: Nos da el plano técnico y la certeza de que la integración de sensores (humedad/temperatura/pH) con un microcontrolador y actuadores hidráulicos es una arquitectura totalmente viable y funcional.  
- Sustento del Enfoque Multivariable: Justifica técnicamente por qué no basta con medir solo el agua; el control del pH y la temperatura es crítico para garantizar la absorción de nutrientes y la salud de la planta.
- Respaldo de Viabilidad: Funciona como un argumento sólido ante jurados o evaluaciones académicas, demostrando que nuestro proyecto está alineado con soluciones tecnológicas patentables y vigentes en el sector agroindustrial.  
- Punto de Partida para Innovar: Al conocer el alcance de su hardware y su app móvil, nos permite enfocarnos en mejorar el software, optimizar la eficiencia de las estructuras hidráulicas o añadir funciones que la patente no cubre.

📄 [Ver patente completa](https://github.com/SharkUsser/FdD_Equipo01/blob/main/Recursos/Patentes/PE20260366A1.pdf)

---

# Patente 3

### Título

### **CN201674848U: 太阳能自动滴灌装置**
*Dispositivo automático de riego por goteo solar*

### Descripción

El invento consiste en un dispositivo automático de riego por goteo alimentado por energía solar fotovoltaica, diseñado específicamente para zonas áridas o desérticas. El sistema consta de una bomba hidráulica conectada a un panel solar que extrae agua desde un pozo profundo hacia un depósito de almacenamiento, el cual integra un sensor de nivel para evitar desbordamientos. El núcleo de automatización opera en dos niveles de control: un controlador central conectado a un sensor de humedad ambiental que activa eléctricamente todo el sistema solo si la humedad del aire es menor al 80%, y un conjunto de sensores de humedad de suelo independientes colocados en la base de cada planta. Estos sensores sectoriales abren mecánicamente sus respectivas válvulas de suministro y goteros individuales únicamente cuando la humedad superficial del suelo cae por debajo del 40%, cerrándolas al superar dicho umbral para garantizar un riego autónomo y eficiente sin intervención humana.
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

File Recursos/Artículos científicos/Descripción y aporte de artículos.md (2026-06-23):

# Artículos Científicos

## Descripción

En esta sección se presentan los artículos científicos utilizados como sustento técnico para el desarrollo del proyecto. Cada artículo aporta información relevante para la selección de tecnologías, el diseño del sistema y la validación de las decisiones de ingeniería implementadas.
<p align="center">
    <a href="https://github.com/SharkUsser/FdD_Equipo01/blob/main/Recursos/Art%C3%ADculos%20cient%C3%ADficos/Art%C3%ADculoCient%C3%ADfico_01.pdf">
    
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

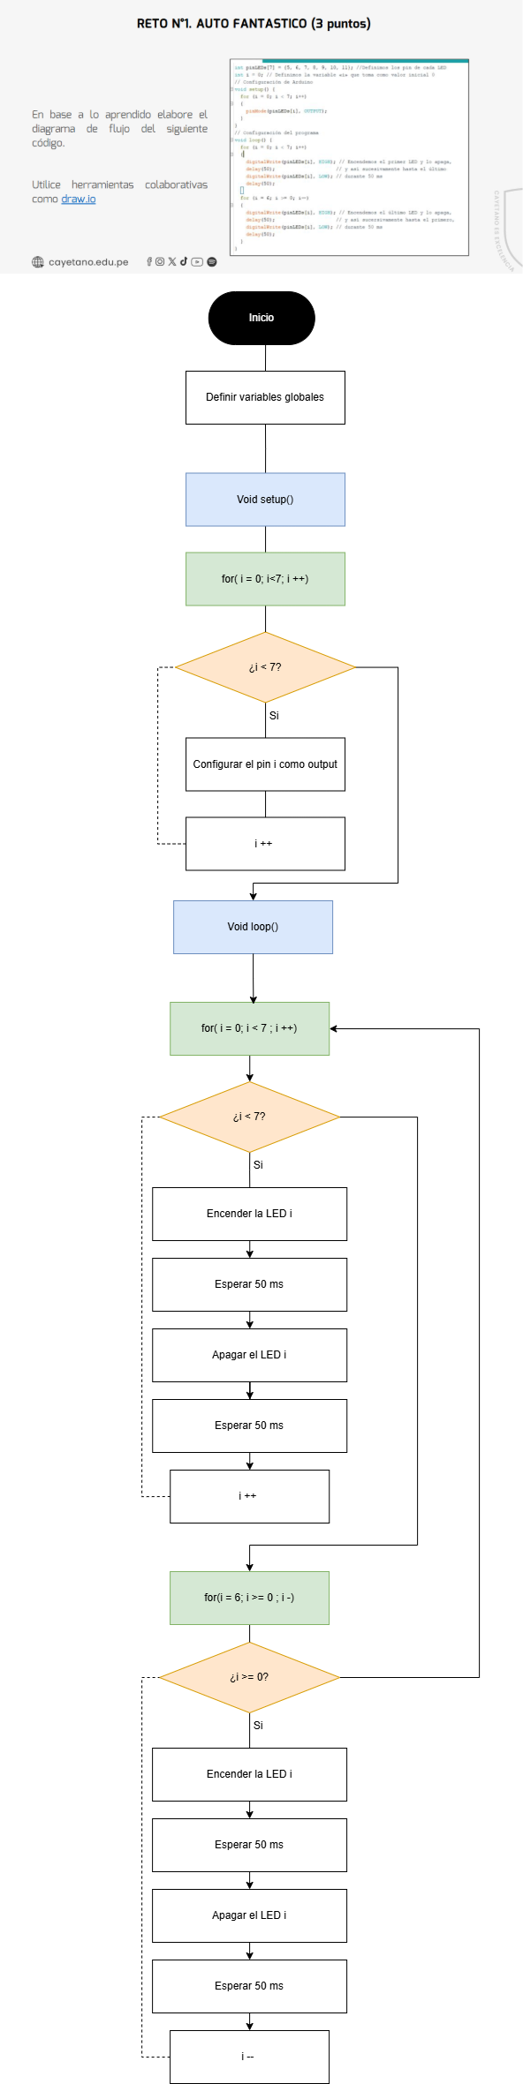
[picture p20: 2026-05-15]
Fundamentos de Diseño/Talleres/Taller_09/Taller_09.drawio.png

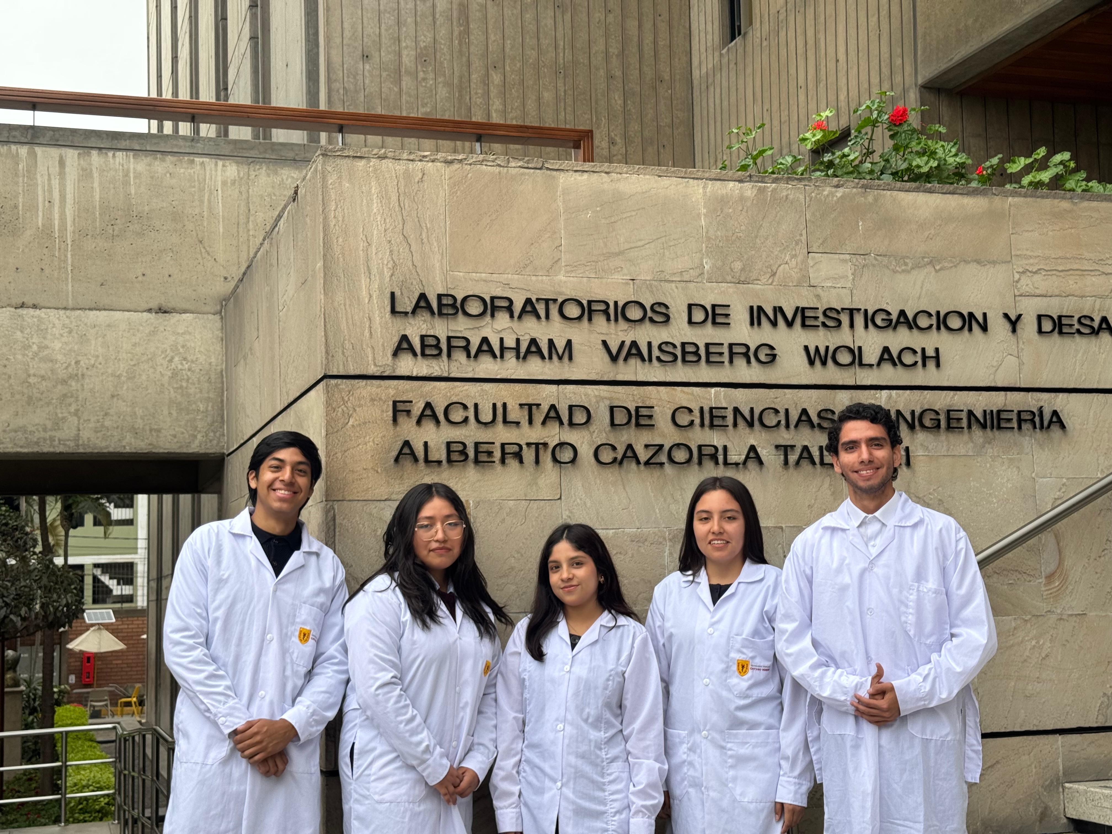
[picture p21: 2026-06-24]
Recursos/Imágenes/Fotos del Grupo/Fotos Grupales/Foto Grupal_bata.jpeg

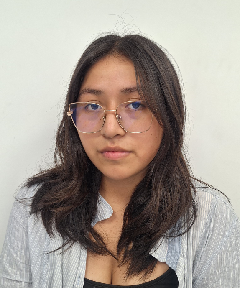
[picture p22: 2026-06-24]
Recursos/Imágenes/Fotos del Grupo/Fotos individuales/Lidia Landa.png

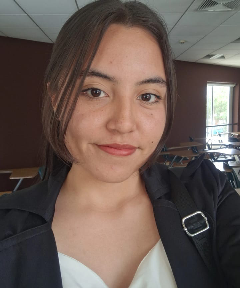
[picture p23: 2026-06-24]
Recursos/Imágenes/Fotos del Grupo/Fotos individuales/Yenifer Loayza.png

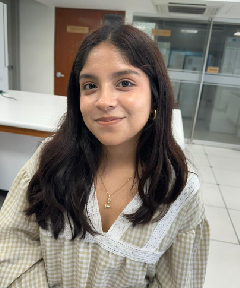
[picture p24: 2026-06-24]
Recursos/Imágenes/Fotos del Grupo/Fotos individuales/Gianella Benites.png

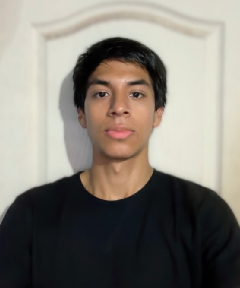
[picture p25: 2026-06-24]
Recursos/Imágenes/Fotos del Grupo/Fotos individuales/Anderson Delerna.png

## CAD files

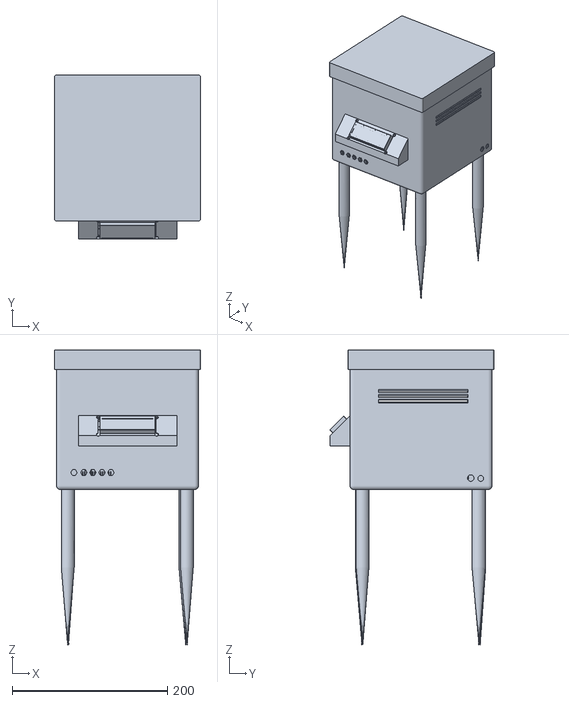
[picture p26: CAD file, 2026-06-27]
Fundamentos de Diseño/Talleres/Taller_10/Onshape_Modelo3D/MODELO_3D_ASSEMBLY.stl
188.0 x 211.3 x 379.6

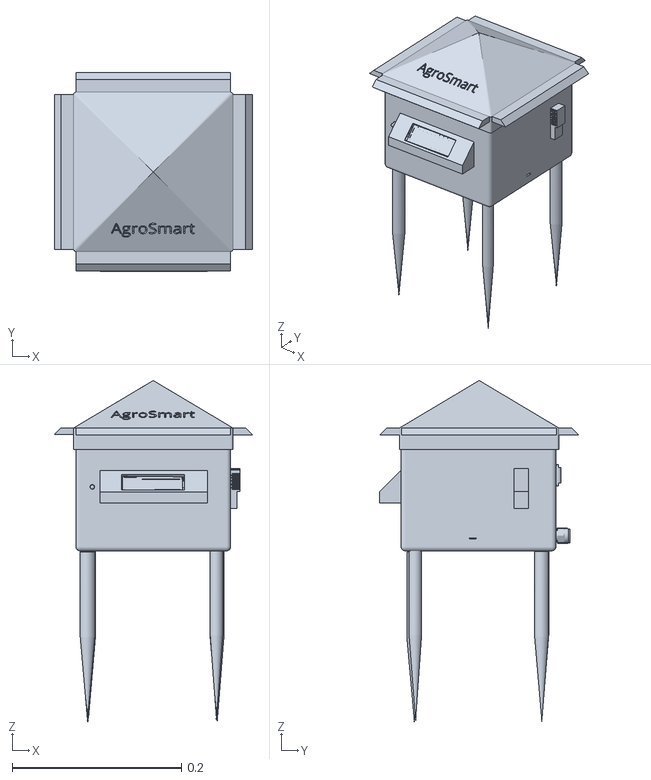
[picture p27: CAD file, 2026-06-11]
Fundamentos de Diseño/Entregables/3er_Entregable/MóduloMecánico/Onshape/Ensamble/AgroSmart.stl
0.234 x 0.235 x 0.403

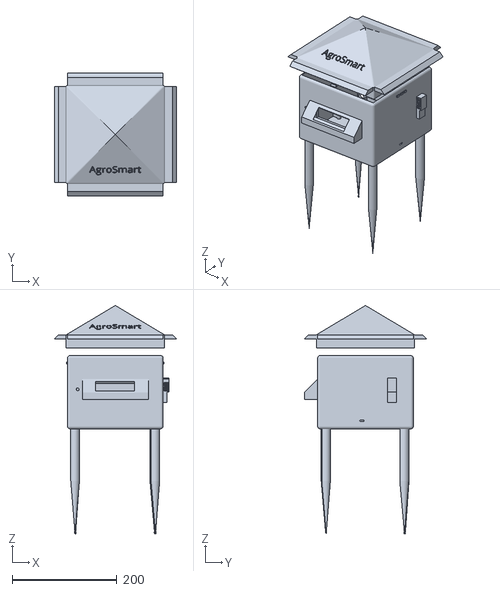
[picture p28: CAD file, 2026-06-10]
Fundamentos de Diseño/Entregables/3er_Entregable/MóduloMecánico/Onshape/Partes/Versión Completa.stl
233.8 x 234.4 x 435.6

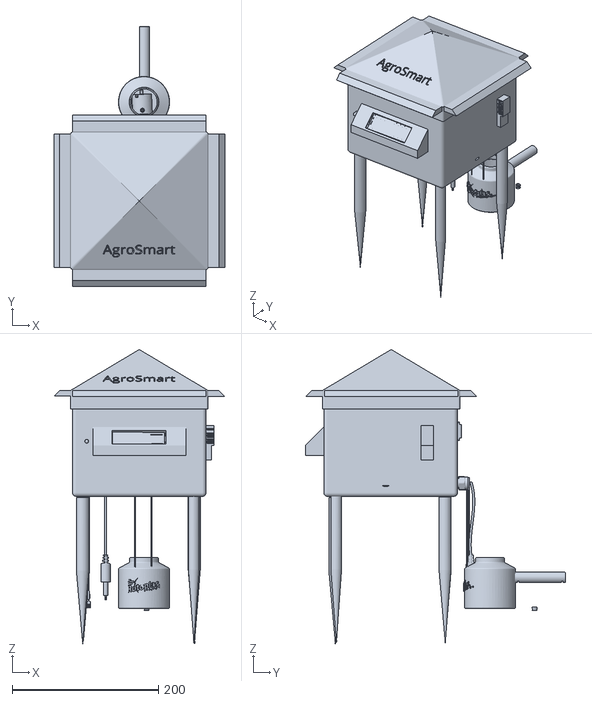
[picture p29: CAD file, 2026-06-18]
Proyecto/MóduloMecánico/V_Final/Onshape/Ensamble/AgroSmart.stl
233.8 x 356.5 x 402.5

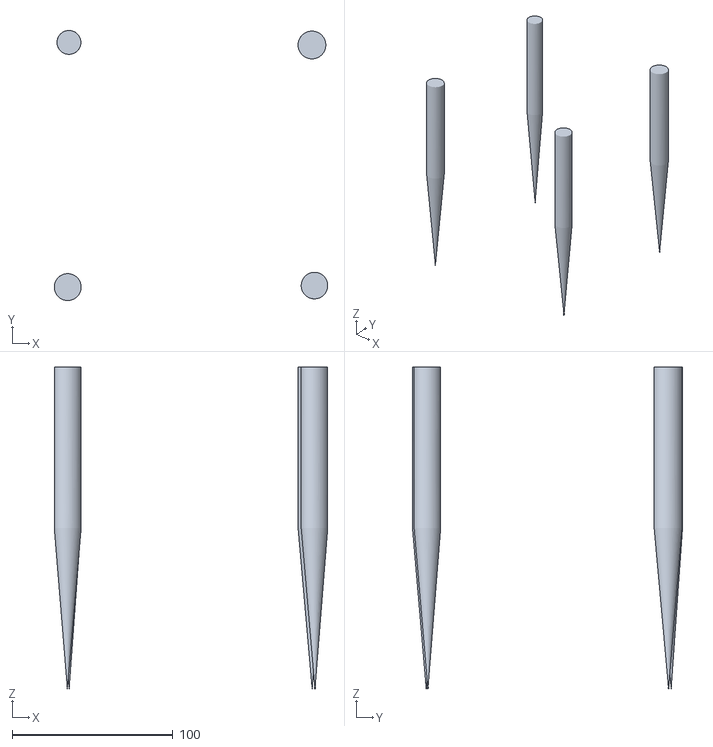
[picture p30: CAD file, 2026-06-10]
Fundamentos de Diseño/Entregables/3er_Entregable/MóduloMecánico/Onshape/Partes/Soportes.stl
169.9 x 167.8 x 200.0

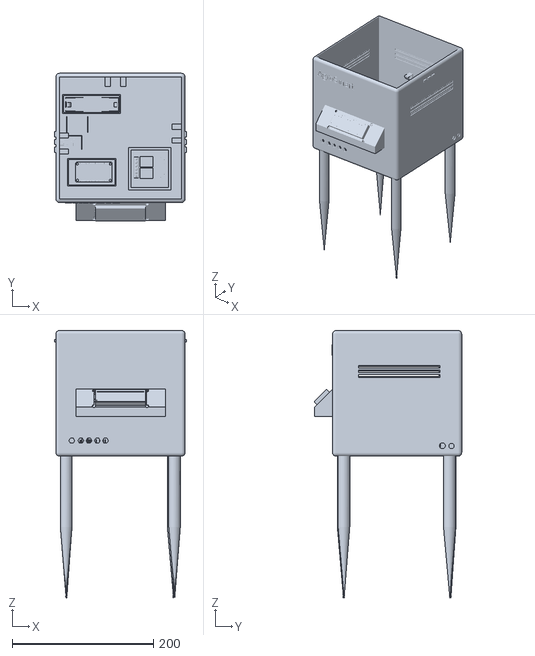
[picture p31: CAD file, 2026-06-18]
Fundamentos de Diseño/Talleres/Taller_10/Onshape_Modelo3D/MODELO_3D_SIN_TAPA_CORREGIDO.stl
186.9 x 208.7 x 377.8

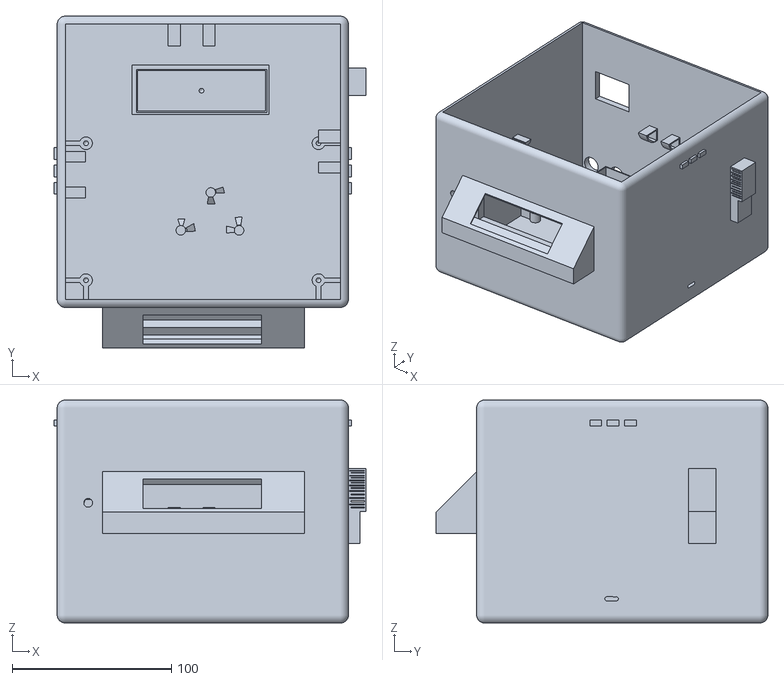
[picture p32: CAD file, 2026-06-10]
Fundamentos de Diseño/Entregables/3er_Entregable/MóduloMecánico/Onshape/Partes/Base.stl
195.9 x 208.3 x 140.0

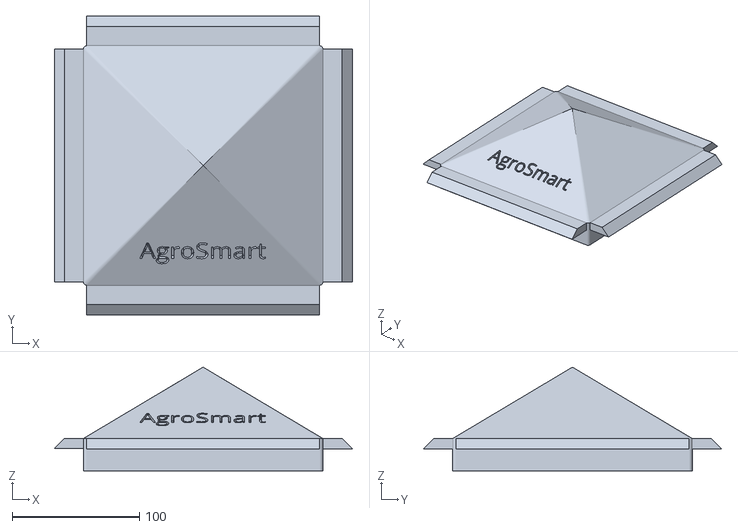
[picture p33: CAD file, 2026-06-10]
Fundamentos de Diseño/Entregables/3er_Entregable/MóduloMecánico/Onshape/Partes/Tapa.stl
233.8 x 234.4 x 81.4

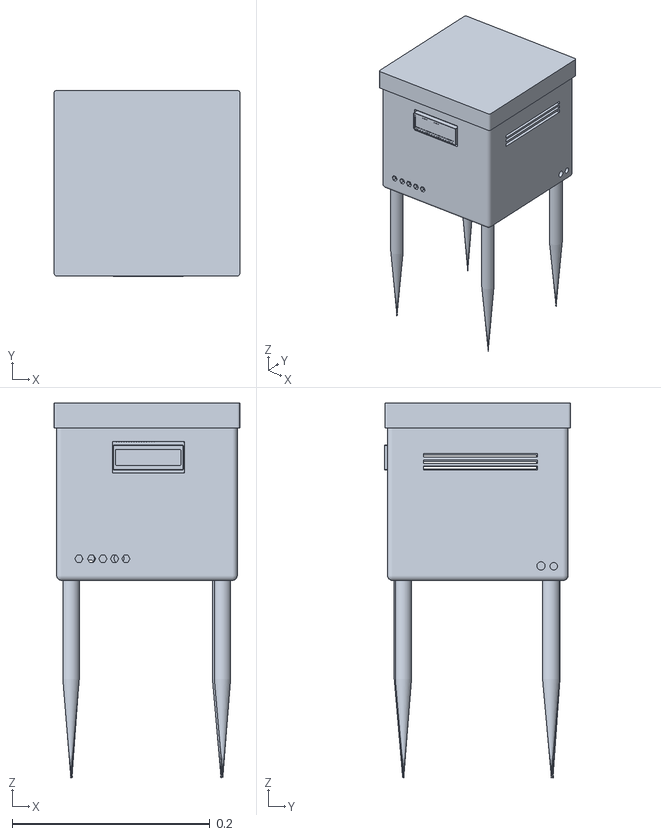
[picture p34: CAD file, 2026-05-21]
Fundamentos de Diseño/Talleres/Taller_10/Onshape_Modelo3D/Con Tapa.stl
0.188 x 0.189 x 0.38

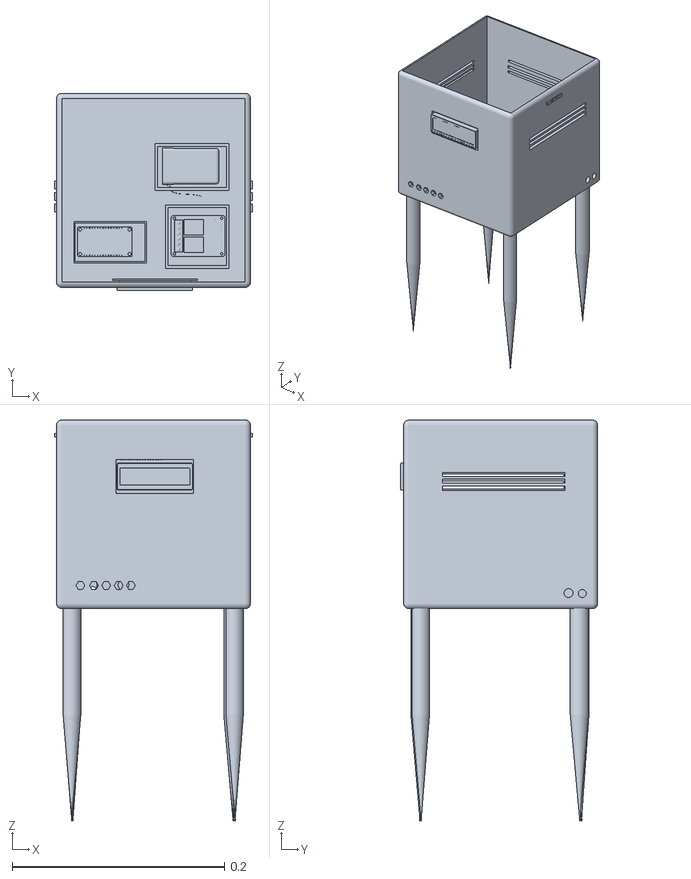
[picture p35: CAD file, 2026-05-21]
Fundamentos de Diseño/Talleres/Taller_10/Onshape_Modelo3D/Sin tapa.stl
0.187 x 0.186 x 0.378

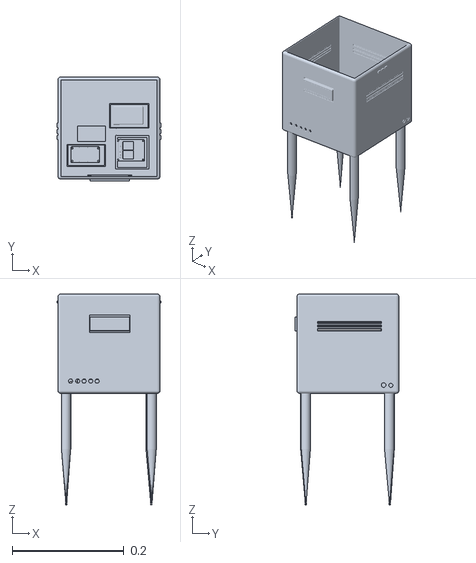
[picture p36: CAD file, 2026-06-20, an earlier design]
Proyecto/MóduloMecánico/V_1.0/Onshape/Ensambles/Assembly.stl
0.187 x 0.186 x 0.378

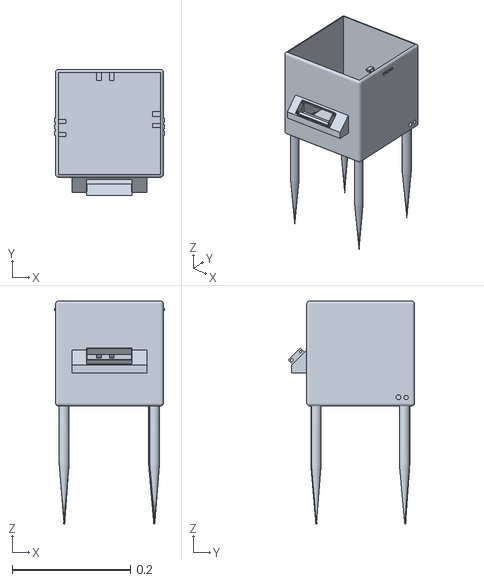
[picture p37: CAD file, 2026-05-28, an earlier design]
Proyecto/MóduloMecánico/V_3.0/Onshape/Partes/Versión 3.1.stl
0.187 x 0.214 x 0.378

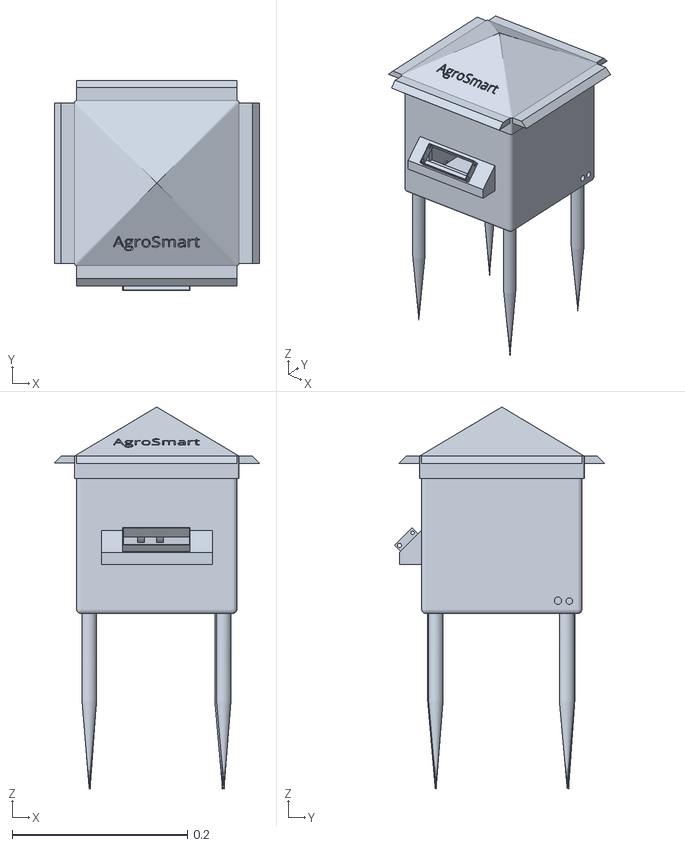
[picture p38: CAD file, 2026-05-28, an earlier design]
Proyecto/MóduloMecánico/V_3.0/Onshape/Partes/Versión 3.1 con tapa.stl
0.234 x 0.24 x 0.436

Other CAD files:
Fundamentos de Diseño/Talleres/Taller_10/Onshape_Modelo3D/MODELO_3D_CON_TAPA_CORREGIDO.stl

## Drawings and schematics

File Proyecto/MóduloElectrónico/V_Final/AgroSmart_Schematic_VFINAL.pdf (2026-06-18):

# Sensor de Conductividad

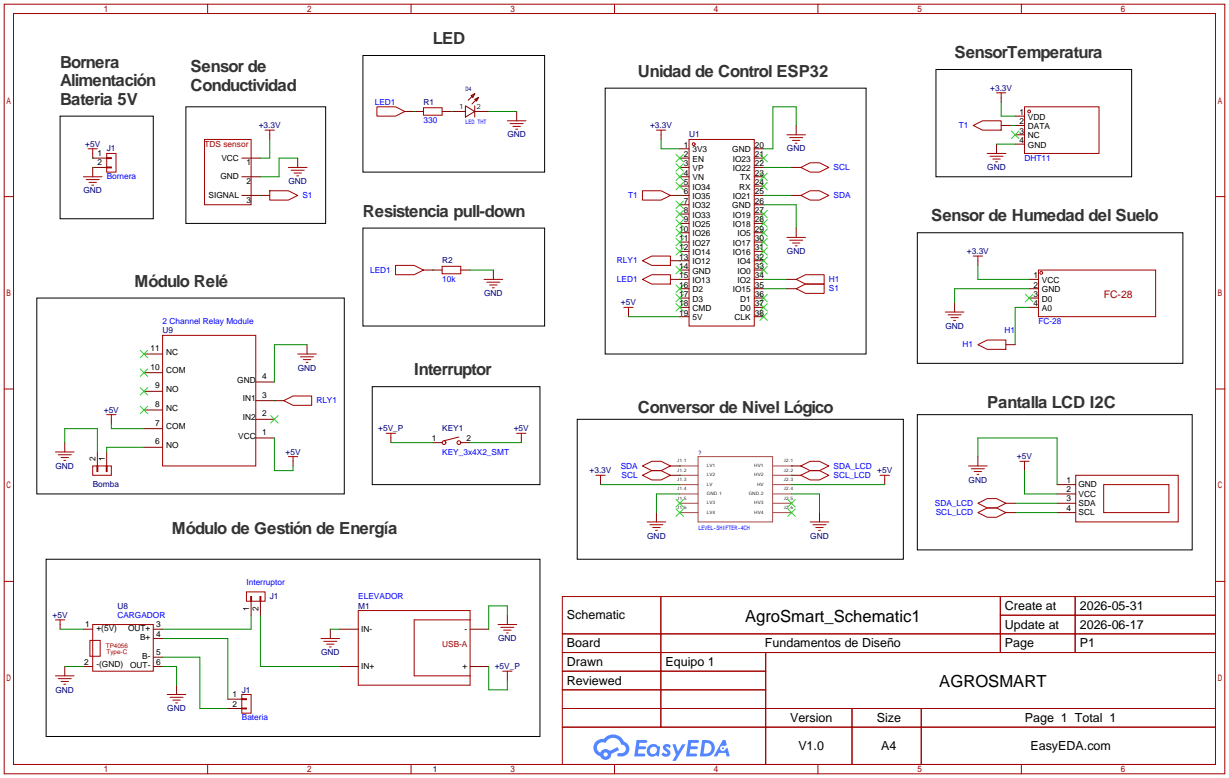
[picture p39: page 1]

Sensor de Humedad del Suelo

Módulo de Gestión de Energía

Schematic | AgroSmart_Schematic1 | Create at | 2026-05-31

Update at | 2026-06-17

Board | Fundamentos de Diseño | Page | P1
Drawn | Equipo 1 | AGROSMART
Reviewed

Version | Size | Page 1 Total 1
V1.0 | A4 | EasyEDA.com

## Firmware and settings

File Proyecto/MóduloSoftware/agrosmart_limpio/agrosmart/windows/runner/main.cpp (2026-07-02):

#include <flutter/dart_project.h>
#include <flutter/flutter_view_controller.h>
#include <windows.h>

#include "flutter_window.h"
#include "utils.h"

int APIENTRY wWinMain(_In_ HINSTANCE instance, _In_opt_ HINSTANCE prev,
                      _In_ wchar_t *command_line, _In_ int show_command) {
  // Attach to console when present (e.g., 'flutter run') or create a
  // new console when running with a debugger.
  if (!::AttachConsole(ATTACH_PARENT_PROCESS) && ::IsDebuggerPresent()) {
    CreateAndAttachConsole();
  }

  // Initialize COM, so that it is available for use in the library and/or
  // plugins.
  ::CoInitializeEx(nullptr, COINIT_APARTMENTTHREADED);

  flutter::DartProject project(L"data");

  std::vector<std::string> command_line_arguments =
      GetCommandLineArguments();

  project.set_dart_entrypoint_arguments(std::move(command_line_arguments));

  FlutterWindow window(project);
  Win32Window::Point origin(10, 10);
  Win32Window::Size size(1280, 720);
  if (!window.Create(L"agrosmart", origin, size)) {
    return EXIT_FAILURE;
  }
  window.SetQuitOnClose(true);

  ::MSG msg;
  while (::GetMessage(&msg, nullptr, 0, 0)) {
    ::TranslateMessage(&msg);
    ::DispatchMessage(&msg);
  }

  ::CoUninitialize();
  return EXIT_SUCCESS;
}

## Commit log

2026-03-20 modificacion de lider
2026-03-20 cambio de lidia
2026-03-20 Agregué archivo de prueba
2026-03-26 Update image in README with new prototype example
2026-04-24 Rename Taller_06.md to Taller_06 : Pitch .md
2026-04-30 Rename FundDiseño/Talleres/Taller_06 docs/README.md to FundDiseño/Talleres/Taller_06 docs/carpeta_actual/archivo.docx → taller_07/archivo.docx
2026-05-01 Rename Taller_06 : Pitch .md to Taller_06_Pitch .md
2026-05-01 Organizacion de los talleres
2026-06-10 organización2
    [Base.stl, Tapa.stl]
2026-06-10 Agregar esquemáticos de AgroSmart versiones 3.0 y 4.0
2026-06-10 organización4
    [Base.stl, Tapa.stl]
2026-06-10 organización7
    [SOPORTES.stl, VERSIÓN COMPLETA.stl]
2026-06-10 organización8
    [Versión Completa.stl]
2026-06-11 fet.integracion de bocetos
2026-06-11 fet.integracion de bocetos1
2026-06-11 fet.integracion de ensamble
    [AgroSmart.stl]
2026-06-27 Agrega entregables y esquematicos de AgroSmart
    [AgroSmart.stl, Base.stl, Con Tapa.stl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]
2026-07-02 Agregar proyecto agrosmart y notebook de ML
